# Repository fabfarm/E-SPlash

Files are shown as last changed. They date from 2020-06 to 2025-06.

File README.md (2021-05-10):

# FabLab Irrigation System

## Design

C++ for a Microprocessor that includes an embedded http server.

The http server displays controls for N zones, where each zone has:

- turn on time
- turn on duration

```
Valve1 \
Valve2  --- Microprocessor <==> Web Interface  
ValveN /
```

## Web server methods

| **Endpoint** | **Purpose** |
|---|---|
| /getData | returns json |
| /updateData  | gets updated json |

## Core Logic

1) start with our json object.
2) we get new data (temp/humidit/y/relay status)
3) update the json object
4) serialize ==> json
5) return json to html

**State Problem**  
When the microcontroller loses power, we lose state. We therefore need to persist settings to disk.

- Settings are *read* from disk on startup
- Settings are *saved* each time a user changes settings in the web ui
- Settings are kept in memory and we check against them

Psuedo code:
```
Startup: 
  - read json to doc obj
  - init wifi
  - init http server

/getData
  - serialize doc obj to Json
  - return Json to caller
  - no logic

/updateData 
  - take incoming Json and save it to disk
  - arduinoJson magically serializes incoming request to our doc object for free
  - no logic 

Loop (no disk i/o):
  - examine current state of in memory doc object and take action
```

## Data format

```json
{
    "data": {
        "currentTime": "Tuesday, June 23 2020 11:54:16",
        "temperature": "29.90",
        "humidity": "51.00",
        "override": 0,
        "ssid": "myssid",
        "pass": "my password"
    },
    "relays": [
        {
            "name": "Fruit Tree",
            "pin": 25,
            "isRunning": 1,
            "isEnabled": 0,
            "times": [
                {
                    "startTime": "03:00",
                    "duration": "0"
                }
            ]
        },
        {
            "name": "Vegie Garden",
            "pin": 26,
            "isRunning": 1,
            "isEnabled": 0,
            "status": 1,
            "times": [
                {
                    "startTime": "12:00",
                    "duration": "0"
                },
                {
                    "startTime": "12:30",
                    "duration": "0"
                }
            ]
        },
        {
            "name": "Cypress Hill",
            "pin": 33,
            "isRunning": 1,
            "isEnabled": 0,
            "status": 1,
            "times": [
                {
                    "startTime": "12:45",
                    "duration": "0"
                },
                {
                    "startTime": "10:00",
                    "duration": "0"
                },
                {
                    "startTime": "16:45",
                    "duration": "0"
                }
            ]
        }
    ]
}

```

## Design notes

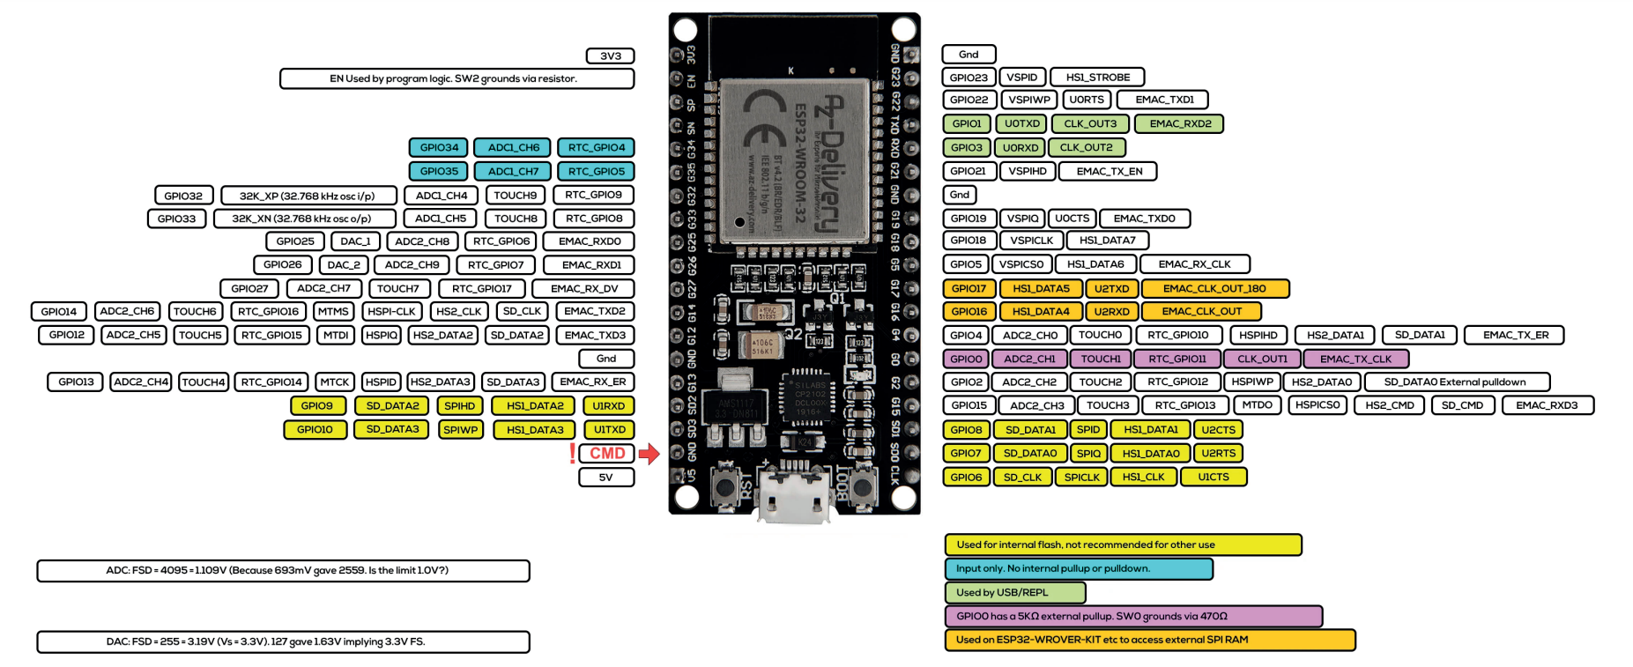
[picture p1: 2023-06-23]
Firmware/temp/Screenshot 2023-06-19 192932.png

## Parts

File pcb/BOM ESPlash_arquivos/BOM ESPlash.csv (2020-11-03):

Value | Coluna1 | Package | Description | Qty | Unit Price | Total Price
PCB blank |  |  | Proto Board Copper Clad FR1, Single Sided, 1 oz. 5.00" x 4.00" (127.0mm x 101.6mm) | 1 | $2.44 | $2.44
FTDI-SMD-HEADER |  | 1X06SMD | CONN HEADER R/A 6POS 2.54MM | 1 | $0.18 | $0.18
22-23-2021 |  | 22-23-2021 | CONN HEADER VERT 2POS 2.54MM | 1 | $0.17 | $0.17
header2x6 |  | 2X03 | CONN HEADER VERT 6POS 2.54MM | 2 | $0.48 | $0.96
SWITCH | SWITCH | SWITCH TACTILE SPST-NO 50MA 12V | SWITCH TACTILE SPST-NO 50MA 12V | 2 | $0.20 | $0.40
0.1uF | Capacitor | C1206FAB | CAP CER 0.1UF 50V X7R 1206 | 2 | $0.11 | $0.22
100uF | Capacitor | C1206FAB | CAP CER 100UF 10V X5R 1206 | 1 | $1.49 | $1.49
15pf | Capacitor | C1206FAB | CAP CER 15PF 50V 1206 | 2 | $0.19 | $0.38
1nF | Capacitor | C1206FAB | CAP CER 1206 1NF 250V X7R 10% | 1 | $0.27 | $0.27
ESP32-WROOM-32 (16MB) |  | ESP-WROOM-32 | WIFI MODULE 128MBITS SPI FLASH | 1 | $4.50 | $4.50
LED | LED | LED1206 | Standard LEDs - SMD 1206 Blue | 7 | $1.45 | $10.15
100ohm | Resistor | R1206 | RES SMD 100 OHM 1% 1/4W 1206 | 5 | $0.57 | $2.85
10k | Resistor | R1206 | RES SMD 10K OHM 1% 1/4W 1206 | 3 | $0.57 | $1.71
1.2Mohm | Resistor | R1206 | RES SMD 1.2M OHM 1% 1/4W 1206 | 1 | $0.10 | $0.10
1.5Mohm | Resistor | R1206 | RES SMD 1.5M OHM 1% 1/4W 1206 | 1 | $0.18 | $0.18
150ohm | Resistor | R1206 | RES SMD 15 OHM 1% 1/4W 1206 | 2 | $0.10 | $0.20
1K | Resistor | R1206 | RES SMD 1K OHM 1% 1/4W 1206 | 4 | $0.57 | $2.28
220omh | Resistor | R1206 | RES SMD 220 OHM 1% 1/4W 1206 | 4 | $0.10 | $0.40
SRD-05VDC-SL-C | Relay | RELAY_SRD-05VDC-SL-C | SRD-5VDC-SL-C 5 Pin PCB Type | 4 | $1.99 | $7.96
ACS712 |  | SO08 | SENSOR CURRENT HALL 20A AC/DC | 1 | $2.32 | $2.32
 |  | SOD123 | DIODE GEN PURP 100V 200MA SOD123 | 4 | $0.13 | $0.52
EL817(S)(D)(TU)-V |  | SOIC254P1030X460-4N | OPTOISOLTR 5KV TRANSISTOR 4-DIP | 4 | $0.18 | $0.72
BCX70SMD |  | SOT23 | TRANS NPN 45V 0.1A SOT23 | 4 | $0.19 | $0.76
MCP1700T-3302E/TT |  | SOT95P237X112-3N | IC REG LINEAR 3.3V 250MA SOT23-3 | 1 | $0.37 | $0.37
TEMP-HUM-SENSOR-DHT11 |  | TEMP-HUM-SENSOR-DHT11 | SENSOR HUMID/TEMP 5V DTL 5% MOD | 1 | $5.00 | $5.00
 |  | W237-102 | WAGO SCREW CLAMP | 4 | $0.10 | $0.40
ECS-.327-12.5-13X |  | XTAL_ECS-.327-12.5-13X | CRYSTAL 32.7680KHZ 12.5PF TH | 1 | $0.24 | $0.24
 |  |  |  |  | Total | $44.73

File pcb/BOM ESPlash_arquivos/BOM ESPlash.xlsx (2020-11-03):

Value | Package | Description | Links | Qty | Unit Price | Total Price
PCB blank |  | Proto Board Copper Clad FR1, Single Sided, 1 oz. 5.00" x 4.00" (127.0mm x 101.6mm) (https://www.digikey.com/product-detail/en/bantam-tools/MT1004/1932-1038-ND/8567212) | https://www.digikey.com/product-detail/en/bantam-tools/MT1004/1932-1038-ND/8567212 | 1 | $2.44 | $2.44
FTDI-SMD-HEADER | 1X06SMD | CONN HEADER R/A 6POS 2.54MM (https://www.digikey.com/product-detail/en/adam-tech/PH1RB-06-UA/2057-PH1RB-06-UA-ND/9830592) | https://www.digikey.com/product-detail/en/adam-tech/PH1RB-06-UA/2057-PH1RB-06-UA-ND/9830592 | 1 | $0.18 | $0.18
22-23-2021 | 22-23-2021 | CONN HEADER VERT 2POS 2.54MM (https://www.digikey.com/products/en?keywords=22-23-2021) | https://www.digikey.com/products/en?keywords=22-23-2021 | 1 | $0.17 | $0.17
header2x6 | 2X03 | CONN HEADER VERT 6POS 2.54MM (https://www.digikey.com/product-detail/en/samtec-inc/TSW-103-07-F-D/SAM10846-ND/2685876) | https://www.digikey.com/product-detail/en/samtec-inc/TSW-103-07-F-D/SAM10846-ND/2685876 | 2 | $0.48 | $0.96
SWITCH | SWITCH TACTILE SPST-NO 50MA 12V | SWITCH TACTILE SPST-NO 50MA 12V (https://www.digikey.com/product-detail/en/e-switch/TL3305BF260QG/EG5354CT-ND/5816199) | https://www.digikey.com/product-detail/en/e-switch/TL3305BF260QG/EG5354CT-ND/5816199 | 2 | $0.20 | $0.40
0.1uF | C1206FAB | CAP CER 0.1UF 50V X7R 1206 (https://www.digikey.com/product-detail/en/kemet/C1206C104K5RAC7800/399-C1206C104K5RAC7800CT-ND/411524) | https://www.digikey.com/product-detail/en/kemet/C1206C104K5RAC7800/399-C1206C104K5RAC7800CT-ND/411524 | 2 | $0.11 | $0.22
100uF | C1206FAB | CAP CER 100UF 10V X5R 1206 (https://www.digikey.com/product-detail/en/tdk-corporation/C3216X5R1A107M160AC/445-6007-1-ND/2444048) | https://www.digikey.com/product-detail/en/tdk-corporation/C3216X5R1A107M160AC/445-6007-1-ND/2444048 | 1 | $1.49 | $1.49
15pf | C1206FAB | CAP CER 15PF 50V 1206 (https://www.digikey.com/product-detail/en/kemet/C1206C150K5GACTU/399-9314-1-ND/3522832) | https://www.digikey.com/product-detail/en/kemet/C1206C150K5GACTU/399-9314-1-ND/3522832 | 2 | $0.19 | $0.38
1nF | C1206FAB | CAP CER 1206 1NF 250V X7R 10% (https://www.digikey.com/product-detail/en/kemet/C1206C102KARECAUTO/399-17173-1-ND/8563714) | https://www.digikey.com/product-detail/en/kemet/C1206C102KARECAUTO/399-17173-1-ND/8563714 | 1 | $0.27 | $0.27
ESP32-WROOM-32 (16MB) | ESP-WROOM-32 | WIFI MODULE 128MBITS SPI FLASH (https://www.digikey.com/product-detail/en/espressif-systems/ESP32-WROOM-32-16MB/1904-1020-2-ND/9381713) | https://www.digikey.com/product-detail/en/espressif-systems/ESP32-WROOM-32-16MB/1904-1020-2-ND/9381713 | 1 | $4.50 | $4.50
LED | LED1206 | Standard LEDs - SMD 1206 Blue (https://eu.mouser.com/productdetail/lumex/sml-lx1206usbc-tr?qs=UWUCXFQQ%252bdkNnUihARaICw==) | https://eu.mouser.com/productdetail/lumex/sml-lx1206usbc-tr?qs=UWUCXFQQ%252bdkNnUihARaICw== | 7 | $1.45 | $10.15
100ohm | R1206 | RES SMD 100 OHM 1% 1/4W 1206 (https://www.digikey.com/product-detail/en/panasonic-electronic-components/ERA-8AEB101V/P100BCCT-ND/3069515) | https://www.digikey.com/product-detail/en/panasonic-electronic-components/ERA-8AEB101V/P100BCCT-ND/3069515 | 5 | $0.57 | $2.85
10k | R1206 | RES SMD 10K OHM 1% 1/4W 1206 (https://www.digikey.com/product-detail/en/bourns-inc/CRT1206-BY-1002ELF/CRT1206-BY-1002ELFCT-ND/1775051) | https://www.digikey.com/product-detail/en/bourns-inc/CRT1206-BY-1002ELF/CRT1206-BY-1002ELFCT-ND/1775051 | 3 | $0.57 | $1.71
1.2Mohm | R1206 | RES SMD 1.2M OHM 1% 1/4W 1206 (https://www.digikey.com/product-detail/en/panasonic-electronic-components/ERJ-8GEYJ125V/P1-2MECT-ND/203263) | https://www.digikey.com/product-detail/en/panasonic-electronic-components/ERJ-8GEYJ125V/P1-2MECT-ND/203263 | 1 | $0.10 | $0.10
1.5Mohm | R1206 | RES SMD 1.5M OHM 1% 1/4W 1206 (https://www.digikey.com/product-detail/en/rohm-semiconductor/KTR18EZPF1504/RHM1-5MAICT-ND/4071441) | https://www.digikey.com/product-detail/en/rohm-semiconductor/KTR18EZPF1504/RHM1-5MAICT-ND/4071441 | 1 | $0.18 | $0.18
150ohm | R1206 | RES SMD 15 OHM 1% 1/4W 1206 (https://www.digikey.com/product-detail/en/yageo/RC1206JR-07150RL/311-150ERCT-ND/732170) | https://www.digikey.com/product-detail/en/yageo/RC1206JR-07150RL/311-150ERCT-ND/732170 | 2 | $0.10 | $0.20
1K | R1206 | RES SMD 1K OHM 1% 1/4W 1206 (https://www.digikey.com/product-detail/en/panasonic-electronic-components/ERA-8AEB102V/P1-0KBCCT-ND/3069520) | https://www.digikey.com/product-detail/en/panasonic-electronic-components/ERA-8AEB102V/P1-0KBCCT-ND/3069520 | 4 | $0.57 | $2.28
220omh | R1206 | RES SMD 220 OHM 1% 1/4W 1206 (https://www.digikey.com/product-detail/en/stackpole-electronics-inc/RMCF1206FT220R/RMCF1206FT220RCT-ND/2418647) | https://www.digikey.com/product-detail/en/stackpole-electronics-inc/RMCF1206FT220R/RMCF1206FT220RCT-ND/2418647 | 4 | $0.10 | $0.40
SRD-05VDC-SL-C | RELAY_SRD-05VDC-SL-C | SRD-5VDC-SL-C 5 Pin PCB Type (https://www.banggood.com/Mini-5V-DC-Power-Relay-SRD-5VDC-SL-C-5-Pin-PCB-Type-p-930170.html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) | https://www.banggood.com/Mini-5V-DC-Power-Relay-SRD-5VDC-SL-C-5-Pin-PCB-Type-p-930170.html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 | 4 | $1.99 | $7.96
ACS712 | SO08 | SENSOR CURRENT HALL 20A AC/DC (https://www.digikey.com/product-detail/en/allegro-microsystems/ACS712ELCTR-20A-T/620-1190-2-ND/1284594) | https://www.digikey.com/product-detail/en/allegro-microsystems/ACS712ELCTR-20A-T/620-1190-2-ND/1284594 | 1 | $2.32 | $2.32
Diode | SOD123 | DIODE GEN PURP 100V 200MA SOD123 (https://www.digikey.com/product-detail/en/on-semiconductor/MMSD4148T1G/MMSD4148T1GOSCT-ND/1121611) | https://www.digikey.com/product-detail/en/on-semiconductor/MMSD4148T1G/MMSD4148T1GOSCT-ND/1121611 | 4 | $0.13 | $0.52
EL817(S)(D)(TU)-V | SOIC254P1030X460-4N | OPTOISOLTR 5KV TRANSISTOR 4-DIP (https://www.digikey.com/product-detail/en/everlight-electronics-co-ltd/EL817/EL817-ND/2693260) | https://www.digikey.com/product-detail/en/everlight-electronics-co-ltd/EL817/EL817-ND/2693260 | 4 | $0.18 | $0.72
BCX70SMD | SOT23 | TRANS NPN 45V 0.1A SOT23 (https://www.digikey.com/product-detail/en/nexperia-usa-inc/BCX70K-215/1727-4918-1-ND/2531422) | https://www.digikey.com/product-detail/en/nexperia-usa-inc/BCX70K-215/1727-4918-1-ND/2531422 | 4 | $0.19 | $0.76
MCP1700T-3302E/TT | SOT95P237X112-3N | IC REG LINEAR 3.3V 250MA SOT23-3 (https://www.digikey.com/product-detail/en/microchip-technology/MCP1700T-3302E-TT/MCP1700T3302ETTCT-ND/652677) | https://www.digikey.com/product-detail/en/microchip-technology/MCP1700T-3302E-TT/MCP1700T3302ETTCT-ND/652677 | 1 | $0.37 | $0.37
TEMP-HUM-SENSOR-DHT11 | TEMP-HUM-SENSOR-DHT11 | SENSOR HUMID/TEMP 5V DTL 5% MOD (https://www.digikey.com/products/en/sensors-transducers/humidity-moisture-sensors/529?k=DHT11) | https://www.digikey.com/products/en/sensors-transducers/humidity-moisture-sensors/529?k=DHT11 | 1 | $5.00 | $5.00
Screw Clamp | W237-102 | WAGO SCREW CLAMP (https://www.aliexpress.com/item/33038876365.html) | https://www.aliexpress.com/item/33038876365.html | 4 | $0.10 | $0.40
ECS-.327-12.5-13X | XTAL_ECS-.327-12.5-13X | CRYSTAL 32.7680KHZ 12.5PF TH (https://www.digikey.com/products/en?keywords=ECS-.327-12.5-13X) | https://www.digikey.com/products/en?keywords=ECS-.327-12.5-13X | 1 | $0.24 | $0.24
 |  |  |  |  | Total | $44.73
Materials and components | What for | Where they come from | Links | Qty | Unit Price | Total Price
MDF Forescolor | for the enclosure | Fablab Stock | http://www.forescolor.com/product/ | 900 | $0.000027 | $0.02
Silicone | for the gasket | fablab stock | https://www.amazon.es/LETS-RESIN-silicona-relaci%C3%B3n-manualmente/dp/B07V5FFPWC | 50 | $0.05 | $2.39
Epoxy resin (https://www.amazon.es/gp/product/B07KQ6Q5CB/ref=ppx_yo_dt_b_asin_title_o04_s00?ie=UTF8&psc=1) | to further waterproof the interior of the enclosure and help with the light refraction of the LEDs | fablab stock | https://www.amazon.es/gp/product/B07KQ6Q5CB/ref=ppx_yo_dt_b_asin_title_o04_s00?ie=UTF8&psc=1 | 50 | $0.01 | $0.60
 |  |  |  |  | Total | $3.01

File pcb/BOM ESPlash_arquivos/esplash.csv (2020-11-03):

Qty | Value | Device | Package | Parts | Description | ARROW_AMERICAS-PURCHASE-URL | AVAILABILITY | DESCRIPTION | DIGIKEY-PURCHASE-URL | MF | MOUSER-PURCHASE-URL | MP | MPN | OC_FARNELL | OC_NEWARK | PACKAGE | POPULARITY | PRICE
4 |  | DIODESOD123 | SOD123 | D1, D2, D3, D4 | DIODE
4 |  | W237-102 | W237-102 | ACIN/OUT, VALVESOLENOID_01, VALVESOLENOID_02, VALVESOLENOID_03 | WAGO SCREW CLAMP |  |  |  |  |  |  |  | 237-102 | unknown | 70K9898
1 | 0.1uF | CAP-UNPOLARIZEDFAB | C1206FAB | C4
1 | 1.2Mohm | RES-US1206FAB | R1206FAB | R7 | Resistor (US Symbol)
1 | 1.5Mohm | RES-US1206FAB | R1206FAB | R9 | Resistor (US Symbol)
1 | 100nF | CAP-UNPOLARIZEDFAB | C1206FAB | C1
3 | 100ohm | RES-US1206 | R1206 | R13, R14, R16 | Resistor (US Symbol)
2 | 100ohm | RES-US1206FAB | R1206FAB | R6, R8 | Resistor (US Symbol)
1 | 100uF | CAP-US1206FAB | C1206FAB | C2
1 | 10K | RES-US1206FAB | R1206FAB | R10 | Resistor (US Symbol)
2 | 10k | RES-US1206 | R1206 | R12, R15 | Resistor (US Symbol)
2 | 150ohm | RES-US1206FAB | R1206FAB | R3, R11 | Resistor (US Symbol)
2 | 15pf | CAP-UNPOLARIZEDFAB | C1206FAB | C5, C6
4 | 1K | RES-US1206FAB | R1206FAB | R1, R2, R4, R5 | Resistor (US Symbol)
1 | 1nF | CAP-UNPOLARIZEDFAB | C1206FAB | C3
1 | 22-23-2021 | 22-23-2021 | 22-23-2021 | POWER | .100 (2.54mm) Center Header - 2 Pin" |  |  |  |  | MOLEX |  |  | 22-23-2021 | 1462926 | 25C3832 |  | 40
4 | 220omh | RES-US1206FAB | R1206FAB | R17, R18, R19, R20 | Resistor (US Symbol)
1 | ACS712 | ACS712 | SO08 | IC1
4 | BCX70SMD | BCX70SMD | SOT23 | Q1, Q2, Q3, Q4 | NPN TRANSISTOR |  |  |  |  |  |  |  |  |  |  |  | 0
1 | ECS-.327-12.5-13X | ECS-.327-12.5-13X | XTAL_ECS-.327-12.5-13X | Y1 | Crystal Cylindrical Can, Radial |  | Unavailable | 32.768kHz ±20ppm Crystal 12.5pF 35 kOhms Cylindrical Can, Radial |  | ECS Inc. |  | ECS-.327-12.5-13X |  |  |  | Cylindrical Can Radial ECS International |  | None
4 | EL817(S)(D)(TU)-V | EL817(S)(D)(TU)-V | SOIC254P1030X460-4N | U2, U3, U4, U5 | Optocoupler DC-IN 1-CH Transistor DC-OUT 4-Pin PDIP Tube |  | Unavailable | Optoisolator Transistor Output 5000Vrms 1 Channel 4-SMD |  | Everlight Electronics |  | EL817(S)(D)(TU)-V |  |  |  | SMD-4 Everlight |  | None
1 | ESP-WROOM-32 | ESP-WROOM-32 | ESP-WROOM-32 | U1 | Espressif Systems ESP-WROOM-32
1 | FTDI-SMD-HEADER | FTDI-SMD-HEADER | 1X06SMD | RTS
1 | GPIO0 Button | 6MM_SWITCH6MM_SWITCH | 6MM_SWITCH | S2 | OMRON SWITCH
3 | LED | LED | LED1206 | U$7, U$9, U$10 | LED
4 | LEDFAB1206 | LEDFAB1206 | LED1206FAB | U$1, U$3, U$4, U$5 | LED
1 | MCP1700T-3302E/TT | MCP1700T-3302E/TT | SOT95P237X112-3N | U$2 |  | https://snapeda.com/shop?store=Arrow+Americas&id=4791194 | Unavailable | IC REG LINEAR 3.3V 250MA SOT23-3 | https://snapeda.com/shop?store=DigiKey&id=4791194 | Microchip Technology | https://snapeda.com/shop?store=Mouser&id=4791194 | MCP1700T-3302E/TT |  |  |  | None |  | None
1 | Reset | 6MM_SWITCH6MM_SWITCH | 6MM_SWITCH | S1 | OMRON SWITCH
4 | SRD-05VDC-SL-C | SRD-05VDC-SL-C | RELAY_SRD-05VDC-SL-C | K1, K2, K3, K4 | 5V Trigger Relay Module For Arduino And Raspberry Pi 5V Trigger Relay Module For Arduino And Raspberry Pi |  | Unavailable | 5V Trigger Relay Module For Arduino And Raspberry Pi 5V Trigger Relay Module For Arduino And Raspberry Pi |  | Songle Relay |  | SRD-05VDC-SL-C |  |  |  | None |  | None
1 | TEMP-HUM-SENSOR-DHT11 | TEMP-HUM-SENSOR-DHT11 | TEMP-HUM-SENSOR-DHT11 | U$6 | DHT11 - digital humidity & temperature sensor
2 | header2x6 | PINHD-2X3 | 2X03 | JP1, JP2 | PIN HEADER |  |  |  |  |  |  |  |  |  |  |  | 62

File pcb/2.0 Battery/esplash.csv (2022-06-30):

Part | Value | Device | Package | Description | ARROW_AMERICAS-PURCHASE-URL | AVAILABILITY | DESCRIPTION | DIGIKEY-PURCHASE-URL | MF | MOUSER-PURCHASE-URL | MP | MPN | OC_FARNELL | OC_NEWARK | PACKAGE | POPULARITY | PRICE
C1 | 100nF | CAP-UNPOLARIZEDFAB | C1206FAB
C2 | 100uF | CAP-US1206FAB | C1206FAB
C5 | 15pf | CAP-UNPOLARIZEDFAB | C1206FAB
C6 | 15pf | CAP-UNPOLARIZEDFAB | C1206FAB
GND1 | SC | W237-103 | W237-103 | WAGO SCREW CLAMP |  |  |  |  |  |  |  | 237-103 | unknown | 18M7116 |  | 5
POWER | 22-23-2021 | 22-23-2021 | 22-23-2021 | .100 (2.54mm) Center Header - 2 Pin" |  |  |  |  | MOLEX |  |  | 22-23-2021 | 1462926 | 25C3832 |  | 40
Q5 | BCX70SMD | BCX70SMD | SOT23 | NPN TRANSISTOR |  |  |  |  |  |  |  |  |  |  |  | 0
Q6 | BCX70SMD | BCX70SMD | SOT23 | NPN TRANSISTOR |  |  |  |  |  |  |  |  |  |  |  | 0
R1 | 100ohm | RES-US1206 | R1206 | Resistor (US Symbol)
R2 | 100ohm | RES-US1206 | R1206 | Resistor (US Symbol)
R4 | 100ohm | RES-US1206 | R1206 | Resistor (US Symbol)
R5 | 100ohm | RES-US1206 | R1206 | Resistor (US Symbol)
R6 | 100ohm | RES-US1206 | R1206 | Resistor (US Symbol)
R7 | 1.2Mohm | RES-US1206FAB | R1206FAB | Resistor (US Symbol)
R8 | 100ohm | RES-US1206 | R1206 | Resistor (US Symbol)
R9 | 1.5Mohm | RES-US1206FAB | R1206FAB | Resistor (US Symbol)
R10 | 10K | RES-US1206FAB | R1206FAB | Resistor (US Symbol)
R11 | 100ohm | RES-US1206 | R1206 | Resistor (US Symbol)
R12 | 10k | RES-US1206 | R1206 | Resistor (US Symbol)
R13 | 100ohm | RES-US1206 | R1206 | Resistor (US Symbol)
R14 | 100ohm | RES-US1206 | R1206 | Resistor (US Symbol)
R15 | 10k | RES-US1206 | R1206 | Resistor (US Symbol)
R16 | 100ohm | RES-US1206 | R1206 | Resistor (US Symbol)
R17 | 100ohm | RES-US1206 | R1206 | Resistor (US Symbol)
R18 | 100ohm | RES-US1206 | R1206 | Resistor (US Symbol)
R19 | 100ohm | RES-US1206 | R1206 | Resistor (US Symbol)
R21 | 10k | RES-US1206 | R1206 | Resistor (US Symbol)
R22 | 10k | RES-US1206 | R1206 | Resistor (US Symbol)
RTS | FTDI-SMD-HEADER | FTDI-SMD-HEADER | 1X06SMD
S1 | Reset | 6MM_SWITCH6MM_SWITCH | 6MM_SWITCH | OMRON SWITCH
S2 | GPIO0 Button | 6MM_SWITCH6MM_SWITCH | 6MM_SWITCH | OMRON SWITCH
SC_00 | SC | W237-103 | W237-103 | WAGO SCREW CLAMP |  |  |  |  |  |  |  | 237-103 | unknown | 18M7116 |  | 5
SC_01 | SC | W237-103 | W237-103 | WAGO SCREW CLAMP |  |  |  |  |  |  |  | 237-103 | unknown | 18M7116 |  | 5
SC_02 | SC | W237-103 | W237-103 | WAGO SCREW CLAMP |  |  |  |  |  |  |  | 237-103 | unknown | 18M7116 |  | 5
SC_03 | SC | W237-103 | W237-103 | WAGO SCREW CLAMP |  |  |  |  |  |  |  | 237-103 | unknown | 18M7116 |  | 5
SC_04 | SC | W237-103 | W237-103 | WAGO SCREW CLAMP |  |  |  |  |  |  |  | 237-103 | unknown | 18M7116 |  | 5
SC_05 | SC | W237-103 | W237-103 | WAGO SCREW CLAMP |  |  |  |  |  |  |  | 237-103 | unknown | 18M7116 |  | 5
SC_06 | SC | W237-103 | W237-103 | WAGO SCREW CLAMP |  |  |  |  |  |  |  | 237-103 | unknown | 18M7116 |  | 5
SC_07 | SC | W237-103 | W237-103 | WAGO SCREW CLAMP |  |  |  |  |  |  |  | 237-103 | unknown | 18M7116 |  | 5
SC_08 | SC | W237-103 | W237-103 | WAGO SCREW CLAMP |  |  |  |  |  |  |  | 237-103 | unknown | 18M7116 |  | 5
U$1 | LED | LED | LED1206 | LED
U$2 | MCP1700T-3302E/TT | MCP1700T-3302E/TT | SOT95P237X112-3N |  | https://snapeda.com/shop?store=Arrow+Americas&id=4791194 | Unavailable | IC REG LINEAR 3.3V 250MA SOT23-3 | https://snapeda.com/shop?store=DigiKey&id=4791194 | Microchip Technology | https://snapeda.com/shop?store=Mouser&id=4791194 | MCP1700T-3302E/TT |  |  |  | None |  | None
U$3 | LED | LED | LED1206 | LED
U$5 | LED | LED | LED1206 | LED
U$6 | TEMP-HUM-SENSOR-DHT11 | TEMP-HUM-SENSOR-DHT11 | TEMP-HUM-SENSOR-DHT11 | DHT11 - digital humidity & temperature sensor
U$7 | LED | LED | LED1206 | LED
U$8 | LED | LED | LED1206 | LED
U$9 | LED | LED | LED1206 | LED
U$10 | LED | LED | LED1206 | LED
U$11 | LED | LED | LED1206 | LED
U$12 | LED | LED | LED1206 | LED
U$13 | LED | LED | LED1206 | LED
U$14 | LED | LED | LED1206 | LED
U$15 | LED | LED | LED1206 | LED
U$16 | LED | LED | LED1206 | LED
U1 | ESP-WROOM-32 | ESP-WROOM-32 | ESP-WROOM-32 | Espressif Systems ESP-WROOM-32
Y1 | ECS-.327-12.5-13X | ECS-.327-12.5-13X | XTAL_ECS-.327-12.5-13X | Crystal Cylindrical Can, Radial |  | Unavailable | 32.768kHz ±20ppm Crystal 12.5pF 35 kOhms Cylindrical Can, Radial |  | ECS Inc. |  | ECS-.327-12.5-13X |  |  |  | Cylindrical Can Radial ECS International |  | None

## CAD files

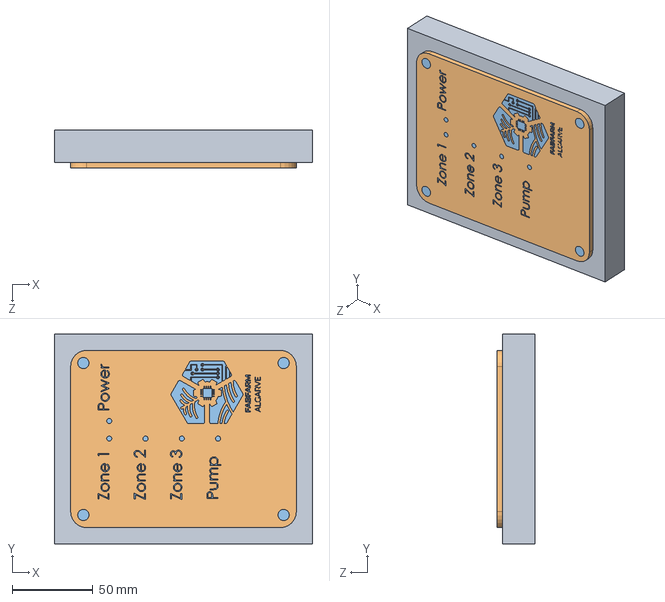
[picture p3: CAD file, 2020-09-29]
board_enclosure/to_cnc.SLDASM
160.0 x 130.0 x 23.5 mm
template
block2

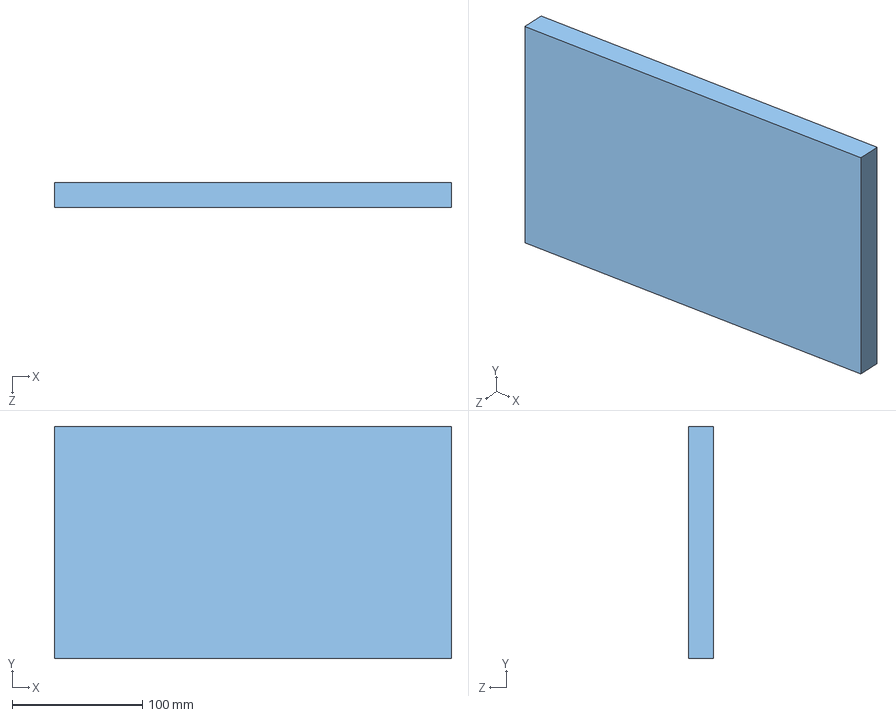
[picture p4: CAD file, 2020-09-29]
board_enclosure/toCNCA.SLDASM
304.4 x 178.2 x 19.0 mm
box_top
box_bottom

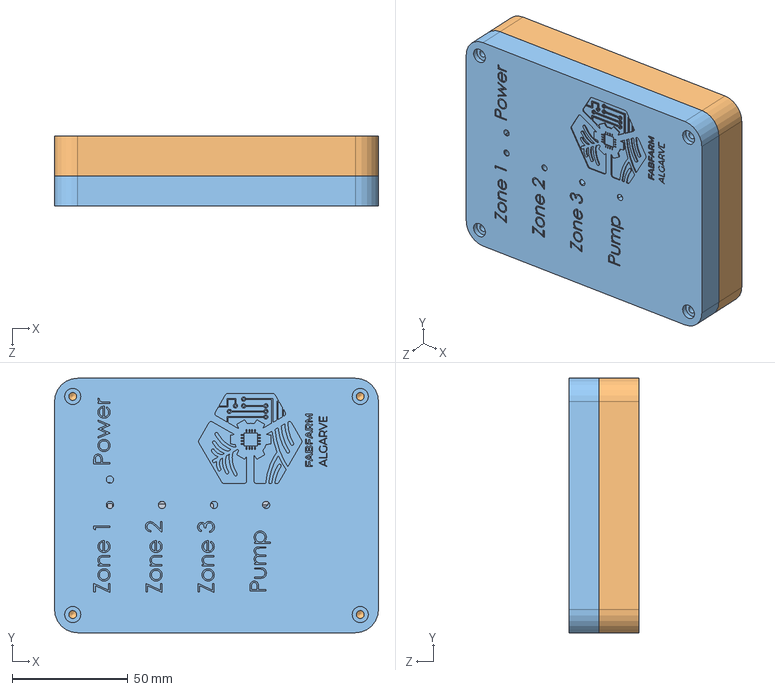
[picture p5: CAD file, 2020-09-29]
board_enclosure/E-SPlash_project.SLDASM
140.0 x 110.0 x 30.4 mm
esplash
box_bottom

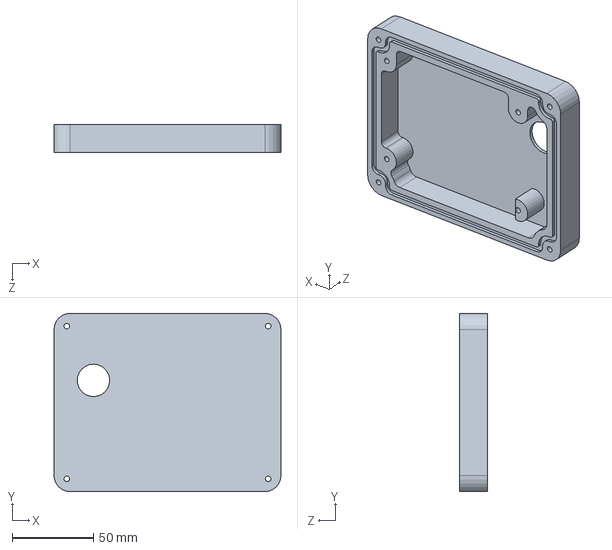
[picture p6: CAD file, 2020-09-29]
board_enclosure/box_bottom.SLDPRT
140.0 x 110.0 x 17.4 mm

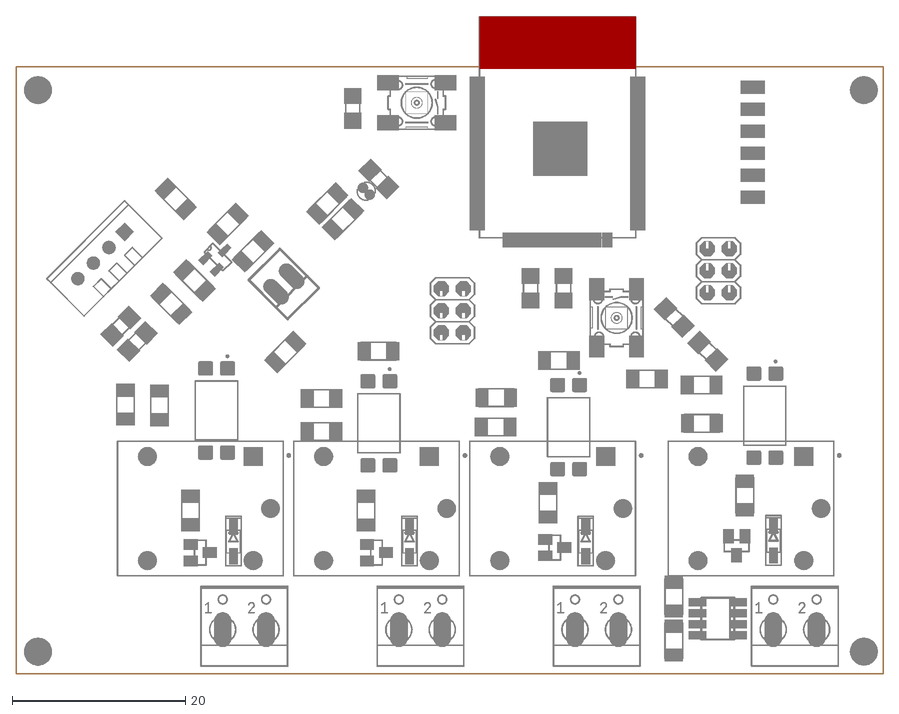
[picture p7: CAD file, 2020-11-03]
pcb/BOM ESPlash_arquivos/esplash.dxf
100.0 x 75.8

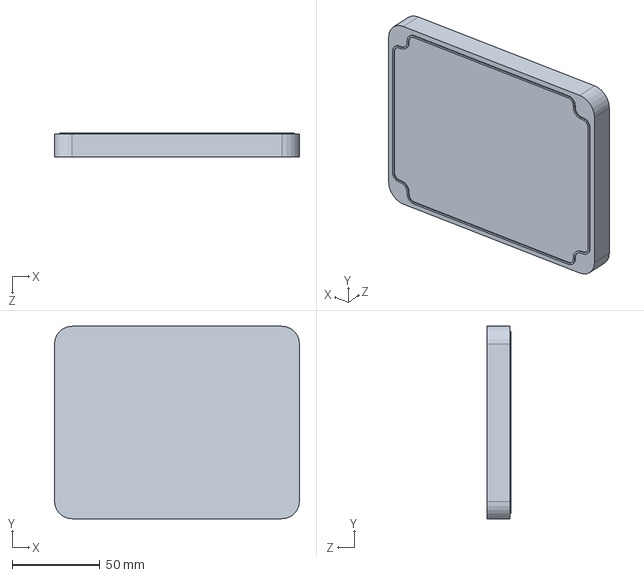
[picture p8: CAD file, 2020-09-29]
board_enclosure/block2.SLDPRT
140.0 x 110.0 x 13.5 mm

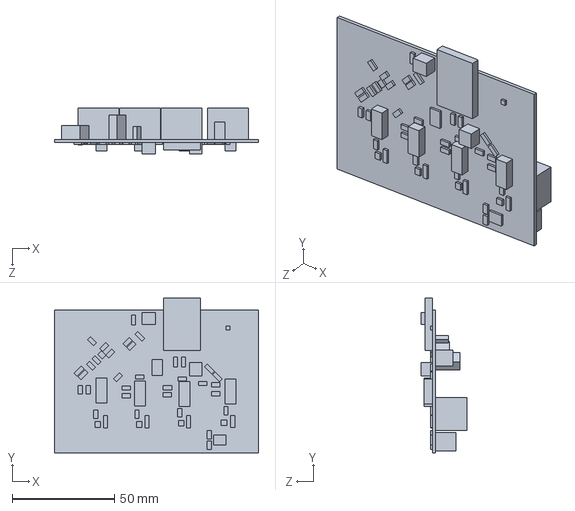
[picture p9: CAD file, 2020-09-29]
board_enclosure/esplash.SLDPRT
100.0 x 75.8 x 22.4 mm

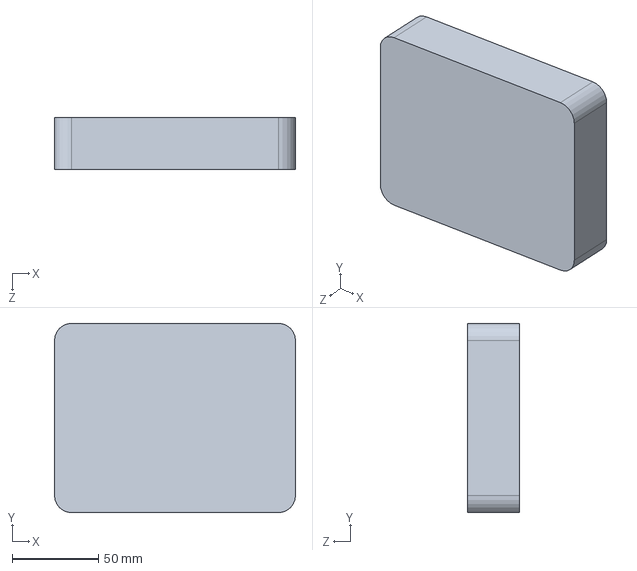
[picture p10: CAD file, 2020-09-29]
board_enclosure/block.SLDPRT
140.0 x 110.0 x 30.0 mm

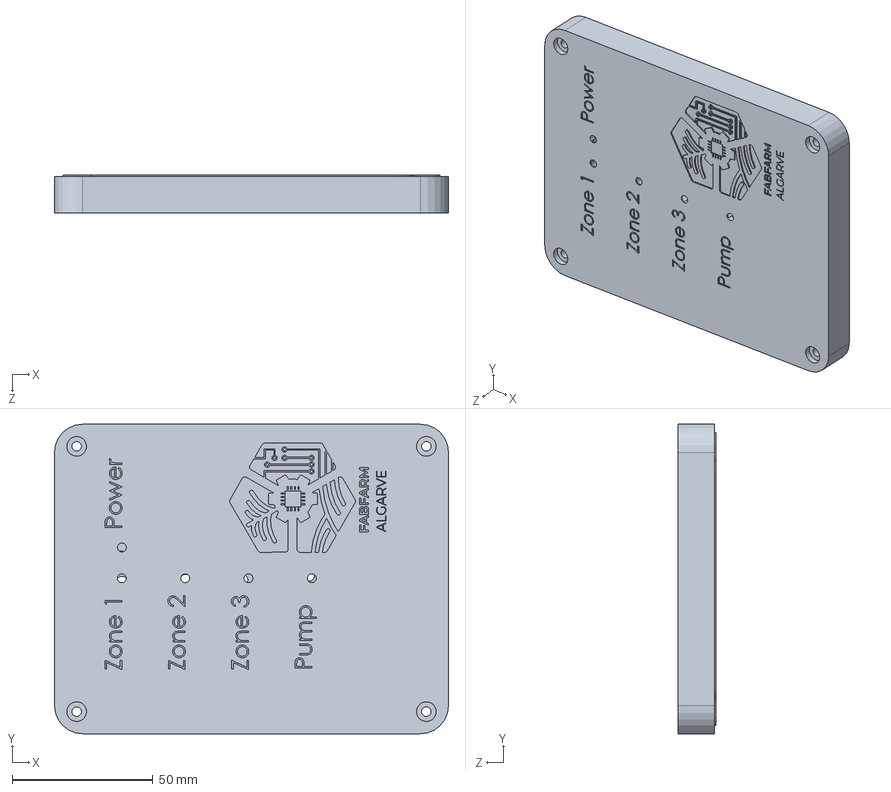
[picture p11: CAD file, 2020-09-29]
board_enclosure/box_top.SLDPRT
140.0 x 110.0 x 13.5 mm

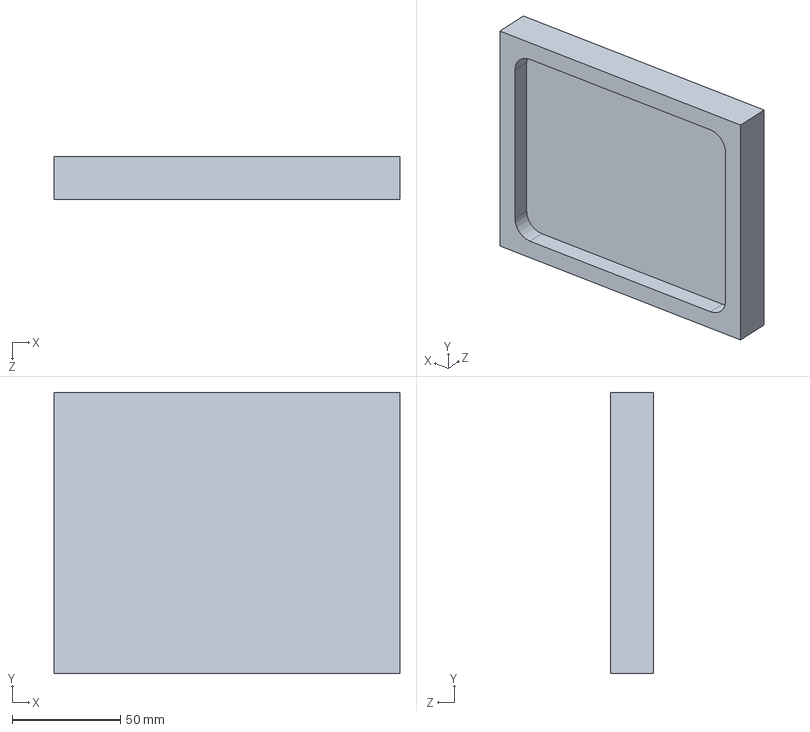
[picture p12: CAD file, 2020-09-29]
board_enclosure/template.SLDPRT
160.0 x 130.0 x 20.0 mm

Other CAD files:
board_enclosure/Part1.SLDPRT
board_enclosure/box_bottom.STL
board_enclosure/box_top.STL

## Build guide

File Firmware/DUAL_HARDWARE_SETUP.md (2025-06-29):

# Dual Hardware Configuration

This project supports two hardware configurations with all pins defined in `platformio.ini`:

## Hardware 1: Custom PCB (Default)
**Environment:** `esp32doit-devkit-v1`

```bash
pio run --environment esp32doit-devkit-v1
# or simply
pio run
```

**Pin Configuration:**
- Relay 1: GPIO 27
- Relay 2: GPIO 26  
- Relay 3: GPIO 25
- Pump: GPIO 33

## Hardware 2: LILYGO T-Relay 4CH
**Environment:** `lilygo-t-relay-4ch`

```bash
pio run --environment lilygo-t-relay-4ch
```

**Pin Configuration:**
- Relay 1: GPIO 21
- Relay 2: GPIO 19
- Relay 3: GPIO 18
- Relay 4: GPIO 5
- Pump: GPIO 21 (same as Relay 1)

## How It Works

All hardware configuration is now handled in `platformio.ini` using build flags:

- All pin definitions are set as `-D` flags in each environment
- WiFi hostname and AP configuration are defined as build flags
- The `T_RELAY_4CH` flag distinguishes between hardware types
- No separate Board_Config files needed - everything is in platformio.ini

## Files Modified

- `platformio.ini`: Contains all pin definitions and configuration strings as build flags
- `Config.cpp`: Uses build flag defines instead of Board_Config structure

## Testing

Both configurations have been tested and compile successfully:
- Custom PCB: ✅ Success (15.65 seconds)
- LILYGO T-Relay: ✅ Success (15.20 seconds)

## Usage

1. **For Custom PCB**: Use default environment or specify `esp32doit-devkit-v1`
2. **For LILYGO T-Relay**: Specify `lilygo-t-relay-4ch` environment

All pin assignments and configurations are automatically applied based on the selected environment.

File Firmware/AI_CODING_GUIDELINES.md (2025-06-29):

# AI Coding Guidelines for FabFarm Irrigation Project

## CRITICAL RULES FOR AI ASSISTANTS

### 1. MAIN.CPP MUST REMAIN CLEAN
**DO NOT add any implementation code to `main.cpp`**

- `main.cpp` contains ONLY function calls
- All logic belongs in separate modules
- Keep the non-monolithic architecture
- New functionality goes in appropriate handler files

**Current main.cpp structure (PRESERVE THIS):**
```cpp
#include "Config.h"

void setup() {
  Serial.begin(9600);
  setupStorage();
  readDataJson();
  configureWiFiSettings();
  scanAvailableWiFiNetworks();
  initiateWiFiConnection();
  disableAllDevices();
  printCompilationTimestamp();
  initializeRtc();
  initializeServer();
  serverHandle();
}

void loop() {
  handleWiFiConnection();
  if (isScheduleMode) {
    scheduleMode();
  }
}
```

### 2. NO DELAY() FUNCTIONS ON ESP32
**NEVER use `delay()` with ESP32 web servers**

- ESP32 with web servers cannot afford to block
- Use `millis()` for timing instead
- Non-blocking code is mandatory

**Example - WRONG:**
```cpp
delay(1000); // NEVER DO THIS
```

**Example - CORRECT:**
```cpp
unsigned long previousMillis = 0;
const long interval = 1000;

unsigned long currentMillis = millis();
if (currentMillis - previousMillis >= interval) {
  previousMillis = currentMillis;
  // Do your timed action here
}
```

### 3. HARDWARE CONFIGURATION (FIXED)
**Pins are HARD-WIRED on PCB - DO NOT CHANGE:**
- Relay 1 (Fruit): Pin 27
- Relay 2 (Vegetables): Pin 26  
- Relay 3 (Water): Pin 25
- Pump: Pin 33

These are defined in `platformio.ini` build flags and cannot be modified.

### 4. MODULAR ARCHITECTURE
**Keep functionality separated in dedicated files:**
- `Config.h/.cpp` - Global configuration and variables
- `Board_Config.h/.cpp` - Hardware abstraction
- `WiFiHandler.h/.cpp` - WiFi management
- `WebServerManager.h/.cpp` - Web server and API endpoints
- `RelayHandler.h/.cpp` - Relay control logic
- `TimeHandler.h/.cpp` - Time and scheduling
- `JsonHandler.h/.cpp` - JSON parsing and creation
- `storageHandler.h/.cpp` - File system operations

### 5. IMPLEMENTATION GUIDELINES
- Add new functions to appropriate handler files
- Declare functions in corresponding `.h` files
- Include necessary headers in `Config.h` if globally needed
- Use consistent naming conventions
- Maintain existing code style

### 6. WEB SERVER CONSIDERATIONS
- All server endpoints in `WebServerManager.cpp`
- Use async web server patterns
- Avoid blocking operations in request handlers
- Keep response times minimal

### 7. WHAT NOT TO DO
- ❌ Add implementation code to `main.cpp`
- ❌ Use `delay()` functions
- ❌ Change hardware pin assignments
- ❌ Create monolithic functions
- ❌ Block the main loop
- ❌ Ignore the modular structure

### 8. WHEN ADDING NEW FEATURES
1. Identify the appropriate handler file
2. Add function declaration to `.h` file
3. Implement function in `.cpp` file
4. Add function call to appropriate location (usually in a handler, not main.cpp)
5. Test compilation
6. Maintain clean separation of concerns

**Remember: This project uses a clean, modular architecture. Keep it that way!**

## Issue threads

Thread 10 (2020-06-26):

if no internet located at boot system won't run

lpgn, 2020-06-26:
system won't run if no wifi connection present at boot, this prevents programs, schedules from running.
I believe I will have to add a battery to the system as a long term solution to keep time without the internet  and as a short term solution I will add a external RCT clock and have the wifi connection not mandatory for system initialization.

Closed 2020-06-26.

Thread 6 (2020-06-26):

relay flickering on, off, on, off...

lpgn, 2020-06-26:
When setting more than one schedule in the same zone with one enabled at x time and other not enabled relay turns on and then off rapidly, this is due to the current logic at the function scheduleMode() the loop has no logic to verify that another schedule is set and ends up turning off. @jknight

jknight, 2020-06-26:
bad code: this will cause checks for different schedules to compete and turn on and off over top of one another:
```
for each relay
    for each schedule
         if we are within this scheduled time then
                turn on
         else
              turn off
```

Good code: instead, we want to check them all first, then make an on/off decision after evaluating all options:

```
for each relay
   enableRelay = false
   for each schedule
       if we are within the scheduled time then
            enableRelay = true
   // done checking all the schedules - do any say we should be on? we only need one ! :)
   if enableRelay then turn on
   else turn off
```

Closed 2020-06-26.

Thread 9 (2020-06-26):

refresh time, humidity, temperature

lpgn, 2020-06-26:
currently data won't refresh without a manual refresh would be convenient to have a auto refresh on web interface.

Closed 2021-07-26.

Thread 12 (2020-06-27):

whachdog crach? reset?

lpgn, 2020-06-27:
Apparently if things hang for to long watchdog resets board. Was facing this from time to time.

Possible problems:
- internet not connected;
- to much delays;
- to much stuff going on in loop;
- wi-fi re-connection routine added to loop might be causing it.

According to this Stack Overflow answer: https://stackoverflow.com/questions/51750377/how-to-disable-interrupt-watchdog-in-esp32-or-increase-isr-time-limit

"You should always structure your code so that you do the least work you can in loop() and let it return. When it returns the software that supports your ESP32 application gets to do important housekeeping tasks, and reset the watchdog timer."

lpgn, 2020-06-27:
Connecting to WiFi..
now Manual Mode
E (56495) task_wdt: Task watchdog got triggered. The following tasks did not reset the watchdog in time:
E (56495) task_wdt:  - async_tcp (CPU 0/1)
E (56495) task_wdt: Tasks currently running:
E (56495) task_wdt: CPU 0: IDLE0
E (56495) task_wdt: CPU 1: IDLE1
E (56495) task_wdt: Aborting.
abort() was called at PC 0x400de5cb on core 0

Backtrace: 0x4008c434:0x3ffbe170 0x4008c665:0x3ffbe190 0x400de5cb:0x3ffbe1b0 0x40084771:0x3ffbe1d0 0x4016f773:0x3ffbc970 0x400df982:0x3ffbc990 0x4008a361:0x3ffbc9b0 0x40088b7d:0x3ffbc9d0

Rebooting...
        \UBV␗|��␞�*@�p␃␜�read file - BEGIN
{"data":{"currentTime":"Saturday, June 27 2020 11:42:59","temperature":"Failed to read temperator from sensor","humidity":"Failed to read humidity from sensor","isScheduleMode":0,"ssid":"rato","pass":"imakestuff","isScheduled":0},"relays":[{"name":"Fruit Tree","pin":27,"isRunning":1,"isEnabled":1,"times":[{"startTime":"11:01","duration":40,"hour":11,"min":1}]},{"name":"Vegie Garden","pin":26,"isRunning":1,"isEnabled":1,"status":1,"times":[{"startTime":"11:02","duration":49,"hour":11,"min":2}]},{"name":"Cypress Hill","pin":25,"isRunning":1,"isEnabled":0,"status":1,"times":[{"startTime":"03:03","duration":60,"hour":3,"min":3},{"startTime":"03:03","duration":60,"hour":3,"min":3}]}]}
read file - COMPLETE
json deserialize test - BEGIN
Connecting to WiFi..

lpgn, 2020-06-27:
I were able to reproduce the problem with good repeatability here are the steps:

1. burn firmware;
2. burn spiffs image;
3. parse initial jason with /updateData;
4. esp32 login to WiFi and all works well so far;
5. disconnect power of board (board loses time);
6. connect to the board thru SoftAP and access thru softAP IP 192.168.4.1;
7. page starts loading stops half way, watchdog intervenes and reboot board with message above;
8. enable the wifi, board connects to wifi (gets internet time) and network IP;
9. page continues loading and problem disappears.

- Probable solutions:
I will try to get time from battery powered rtc clock;

Kashyapkoshti, 2020-08-28:
rst:0x10 (RTCWDT_RTC_RESET),boot:0x1f (SPI_FAST_FLASH_BOOT)
flash read err, 1000
ets_main.c 371

I am getting this error in my esp32 devkit v1
How to solve it?

lpgn, 2020-11-19:
@Kashyapkoshti can you give more details are you trying to implement this project in to a esp32?

Kashyapkoshti, 2020-11-19:
@lpgn  i am using DOIT devkit v1 Esp32 for making remote controlled car with wifi

lpgn, 2021-05-10:
I believe it was solved removing delays

Closed 2021-05-10.

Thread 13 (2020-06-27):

wi-fi ssid and password parsed with json

lpgn, 2020-06-27:
To have a way of changing the wi-fi ssid and password without burning again the firmware is a must. The current problem for this easy implementation is that in first time boot, after a upload of spiffs image there is no Json and thus no way to go into the page and parse the first Json...

lpgn, 2022-03-11:
that first problem is solved with the function implemented some time ago to create a new json file when none is present.

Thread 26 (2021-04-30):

corrupt JSON file

lpgn, 2021-04-30:
after refresh p[age does not rebuild.
We believe its due to hardware and will build another test board to confirm.

jknight, 2021-04-30:
💻 🔥

lpgn, 2021-05-10:
solved 234f2fd

Closed 2021-05-10.

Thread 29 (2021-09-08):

implement pump current feedback

lpgn, 2021-09-08:
By using the current sensor we should be able to obtain feedback if either the pump is running dry or stuck

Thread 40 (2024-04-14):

DHT sensor causing Guru Meditation Error

lpgn, 2024-04-14:
Guru Meditation Error: Core  1 panic'ed (Interrupt wdt timeout on CPU1).

Core  1 register dump:
PC      : 0x400d7d20  PS      : 0x00060135  A0      : 0x800d7df8  A1      : 0x3ffd41b0
A2      : 0x00022165  A3      : 0x00000001  A4      : 0x3ffc4978  A5      : 0xdacae800
A6      : 0x00000000  A7      : 0x40404040  A8      : 0x00027100  A9      : 0x00022165
A10     : 0x00000001  A11     : 0x00000000  A12     : 0x00000000  A13     : 0x00200000
A14     : 0x00000028  A15     : 0x00000001  SAR     : 0x00000015  EXCCAUSE: 0x00000006
EXCVADDR: 0x00000000  LBEG    : 0x40084a05  LEND    : 0x40084a0d  LCOUNT  : 0x00000027

Backtrace: 0x400d7d1d:0x3ffd41b0 0x400d7df5:0x3ffd41d0 0x400d7e85:0x3ffd4330 0x400d43a2:0x3ffd4360 0x400d43f9:0x3ffd4390 0x400d6d72:0x3ffd43b0 0x4018ec67:0x3ffd4430 0x400df475:0x3ffd4450 0x400dd029:0x3ffd44a0 0x400dd139:0x3ffd44f0 0x400dd321:0x3ffd4540 0x4017434d:0x3ffd4560 0x401743c9:0x3ffd4590 0x40174bae:0x3ffd4�

By disabling temperature and humidity read error disappears.

lpgn, 2024-04-14:
addr2line -e .pio/build/esp32doit
-devkit-v1/firmware.elf -a -f 0x400d7d1d:0x3ffd41b0 0x400d7df5:0x3ffd41d0 0x400d7e85:0x3ffd4330 0x400d43a2:0x3ffd4360 0x400d43f9:0x3ffd4390 0x400d6d72:0x3ffd43b0 0x4018ec67:0x3ffd4430 0x400df475:0x3ffd4450 0x400dd029:0x3ffd44a0 0x400dd139:0x3ffd44f0 0x400dd321:0x3ffd4540 0x4017434d:0x3ffd4560 0x401743c9:0x3ffd4590 0x40174bae:0x3ffd4
0x400d7d1d
_ZN3DHT11expectPulseEb
/home/lpgn/gits_go_here_wsl/E-SPlash/Firmware/.pio/libdeps/esp32doit-devkit-v1/DHT sensor library/DHT.cpp:388
0x400d7df5
_ZN3DHT4readEb
/home/lpgn/gits_go_here_wsl/E-SPlash/Firmware/.pio/libdeps/esp32doit-devkit-v1/DHT sensor library/DHT.cpp:306
0x400d7e85
_ZN3DHT15readTemperatureEbb
/home/lpgn/gits_go_here_wsl/E-SPlash/Firmware/.pio/libdeps/esp32doit-devkit-v1/DHT sensor library/DHT.cpp:88
0x400d43a2
_Z11readDHTDatab
/home/lpgn/gits_go_here_wsl/E-SPlash/Firmware/src/fabfarm_irrigation/SetupSensors.cpp:22
0x400d43f9
_Z18readDHTTemperaturev
/home/lpgn/gits_go_here_wsl/E-SPlash/Firmware/src/fabfarm_irrigation/SetupSensors.cpp:44
0x400d6d72
_Z24handleGetDataJsonRequestP21AsyncWebServerRequest
/home/lpgn/gits_go_here_wsl/E-SPlash/Firmware/src/fabfarm_irrigation/WebServerManager.cpp:24
0x4018ec67
_ZNSt17_Function_handlerIFvP21AsyncWebServerRequestEPS2_E9_M_invokeERKSt9_Any_dataOS1_
/home/lpgn/.platformio/packages/toolchain-xtensa-esp32/xtensa-esp32-elf/include/c++/8.4.0/bits/std_function.h:297
0x400df475
_ZNKSt8functionIFvP21AsyncWebServerRequestEEclES1_
/home/lpgn/.platformio/packages/toolchain-xtensa-esp32/xtensa-esp32-elf/include/c++/8.4.0/bits/std_function.h:687
0x400dd029
_ZN21AsyncWebServerRequest10_parseLineEv
/home/lpgn/gits_go_here_wsl/E-SPlash/Firmware/.pio/libdeps/esp32doit-devkit-v1/ESP Async WebServer/src/WebRequest.cpp:581 (discriminator 1)
0x400dd139
_ZN21AsyncWebServerRequest7_onDataEPvj
/home/lpgn/gits_go_here_wsl/E-SPlash/Firmware/.pio/libdeps/esp32doit-devkit-v1/ESP Async WebServer/src/WebRequest.cpp:123
0x400dd321
_ZNSt17_Function_handlerIFvPvP11AsyncClientS0_jEZN21AsyncWebServerRequestC4EP14AsyncWebServerS2_EUlS0_S2_S0_jE6_E9_M_invokeERKSt9_Any_dataOS0_OS2_SC_Oj
/home/lpgn/gits_go_here_wsl/E-SPlash/Firmware/.pio/libdeps/esp32doit-devkit-v1/ESP Async WebServer/src/WebRequest.cpp:76
0x4017434d
_ZNKSt8functionIFvPvP11AsyncClientS0_jEEclES0_S2_S0_j
/home/lpgn/.platformio/packages/toolchain-xtensa-esp32/xtensa-esp32-elf/include/c++/8.4.0/bits/std_function.h:687
0x401743c9
_ZN11AsyncClient7_s_recvEPvP7tcp_pcbP4pbufa
/home/lpgn/gits_go_here_wsl/E-SPlash/Firmware/.pio/libdeps/esp32doit-devkit-v1/AsyncTCP/src/AsyncTCP.cpp:1191
0x40174bae
_ZL19_async_service_taskPv
/home/lpgn/gits_go_here_wsl/E-SPlash/Firmware/.pio/libdeps/esp32doit-devkit-v1/AsyncTCP/src/AsyncTCP.cpp:159

WingCode, 2024-04-15:
Might be related to https://github.com/adafruit/DHT-sensor-library/issues/211

Closed 2024-04-16.

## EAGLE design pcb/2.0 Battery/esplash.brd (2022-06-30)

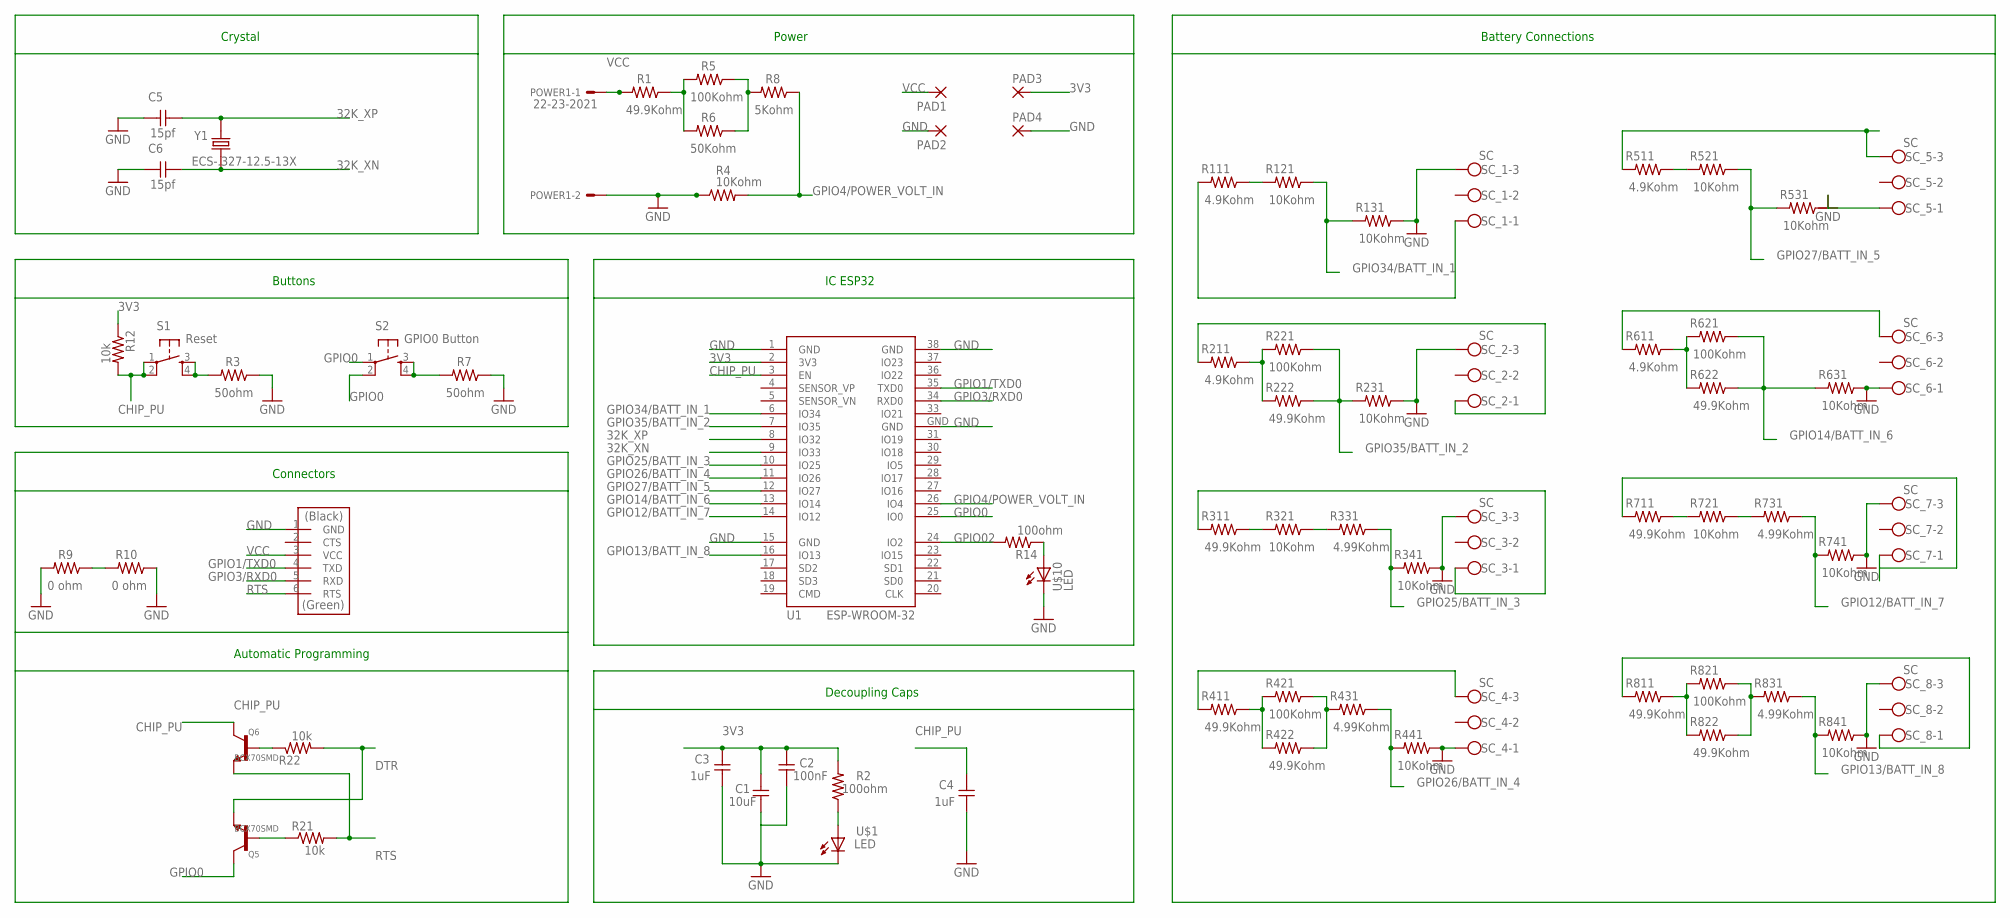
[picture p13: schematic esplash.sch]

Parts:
C1: 10uF; C1206FAB
C2: 100nF; C1206FAB
C3, C4: 1uF; C1206FAB
C5, C6: 15pf; C1206FAB
PAD1, PAD2, PAD3, PAD4: 2,15/1,0
POWER1: 22-23-2021
Q5, Q6: BCX70SMD; SOT23
R1, R222, R311, R411, R422, R622, R711, R811, R822: 49.9Kohm; R1206FAB
R2, R14: 100ohm; R1206
R3, R7: 50ohm; R1206FAB
R4, R121, R131, R231, R321, R341, R441, R521, R531, R631, R721, R741, R841: 10Kohm; R1206FAB
R5, R221, R421, R621, R821: 100Kohm; R1206FAB
R6: 50Kohm; R1206FAB
R8: 5Kohm; R1206FAB
R9, R10: 0 ohm; R1206FAB
R12, R21, R22: 10k; R1206
R111, R211, R511, R611: 4.9Kohm; R1206FAB
R331, R431, R731, R831: 4.99Kohm; R1206FAB
RTS: FTDI-SMD-HEADER; 1X06SMD
S1: Reset; 6MM_SWITCH
S2: GPIO0 Button; 6MM_SWITCH
SC_1, SC_2, SC_3, SC_4, SC_5, SC_6, SC_7, SC_8: SC; W237-103
U1: ESP-WROOM-32
U$1, U$10: LED; LED1206
Y1: ECS-.327-12.5-13X; XTAL_ECS-.327-12.5-13X

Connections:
3V3: C1.2, C2.1, C3.1, PAD3.1, R2.2, R12.1, U1.2 (3V3)
32K_XN: C6.2, U1.9 (IO33), Y1.1
32K_XP: C5.2, U1.8 (IO32), Y1.2
CHIP_PU: C4.1, Q6.3 (C), R12.2, S1.1, S1.2 (P1), U1.3 (EN)
DTR: Q5.2 (E), R22.2
GND: C1.1, C2.2, C3.2, C4.2, C5.1, C6.1, PAD2.1, PAD4.1, POWER1.2, R3.1, R4.1, R7.1, R9.2, R10.1, R131.1, R231.1, R341.1, R441.1, R531.1, R631.1, R741.1, R841.1, RTS.1 (GND), SC_1.3, SC_2.3, SC_3.3, SC_4.1, SC_5.1, SC_6.1, SC_7.3, SC_8.3, U1.1 (GND), U1.15 (GND), U1.38 (GND), U1.GND, U$1.2 (C), U$10.2 (C)
GPIO0: Q5.3 (C), S2.1, S2.2 (P1), U1.25 (IO0)
GPIO1/TXD0: RTS.4 (TXD), U1.35 (TXD0)
GPIO02: R14.2, U1.24 (IO2)
GPIO3/RXD0: RTS.5 (RXD), U1.34 (RXD0)
GPIO4/POWER_VOLT_IN: R4.2, R8.1, U1.26 (IO4)
GPIO12/BATT_IN_7: R731.1, R741.2, U1.14 (IO12)
GPIO13/BATT_IN_8: R831.1, R841.2, U1.16 (IO13)
GPIO14/BATT_IN_6: R621.1, R622.1, R631.2, U1.13 (IO14)
GPIO25/BATT_IN_3: R331.1, R341.2, U1.10 (IO25)
GPIO26/BATT_IN_4: R431.1, R441.2, U1.11 (IO26)
GPIO27/BATT_IN_5: R521.1, R531.2, U1.12 (IO27)
GPIO34/BATT_IN_1: R121.1, R131.2, U1.6 (IO34)
GPIO35/BATT_IN_2: R221.1, R222.1, R231.2, U1.7 (IO35)
unnamed: R1.1, R5.2, R6.2
unnamed: R3.2, S1.3 (S), S1.4 (S1)
unnamed: R111.1, R121.2
unnamed: R14.1, U$10.1 (A)
unnamed: R111.2, SC_1.1
unnamed: R5.1, R6.1, R8.2
unnamed: R211.2, SC_2.1
unnamed: R611.2, SC_6.3
unnamed: R9.1, R10.2
unnamed: R2.1, U$1.1 (A)
unnamed: R211.1, R221.2, R222.2
unnamed: R7.2, S2.3 (S), S2.4 (S1)
unnamed: R311.2, SC_3.1
unnamed: R311.1, R321.2
unnamed: Q5.1 (B), R21.1
unnamed: R321.1, R331.2
unnamed: R411.2, SC_4.3
unnamed: R411.1, R421.2, R422.2
unnamed: Q6.1 (B), R22.1
unnamed: R421.1, R422.1, R431.2
unnamed: R511.1, R521.2
unnamed: R511.2, SC_5.3
unnamed: R611.1, R621.2, R622.2
unnamed: R711.2, SC_7.1
unnamed: R711.1, R721.2
unnamed: R721.1, R731.2
unnamed: R811.2, SC_8.1
unnamed: R811.1, R821.2, R822.2
unnamed: R821.1, R822.1, R831.2
RTS: Q6.2 (E), R21.2, RTS.6 (RTS)
VCC: PAD1.1, POWER1.1, R1.2, RTS.3 (VCC)

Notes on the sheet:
Power
IC ESP32
Crystal
Buttons
Connectors
Battery Connections
Automatic Programming
Decoupling Caps

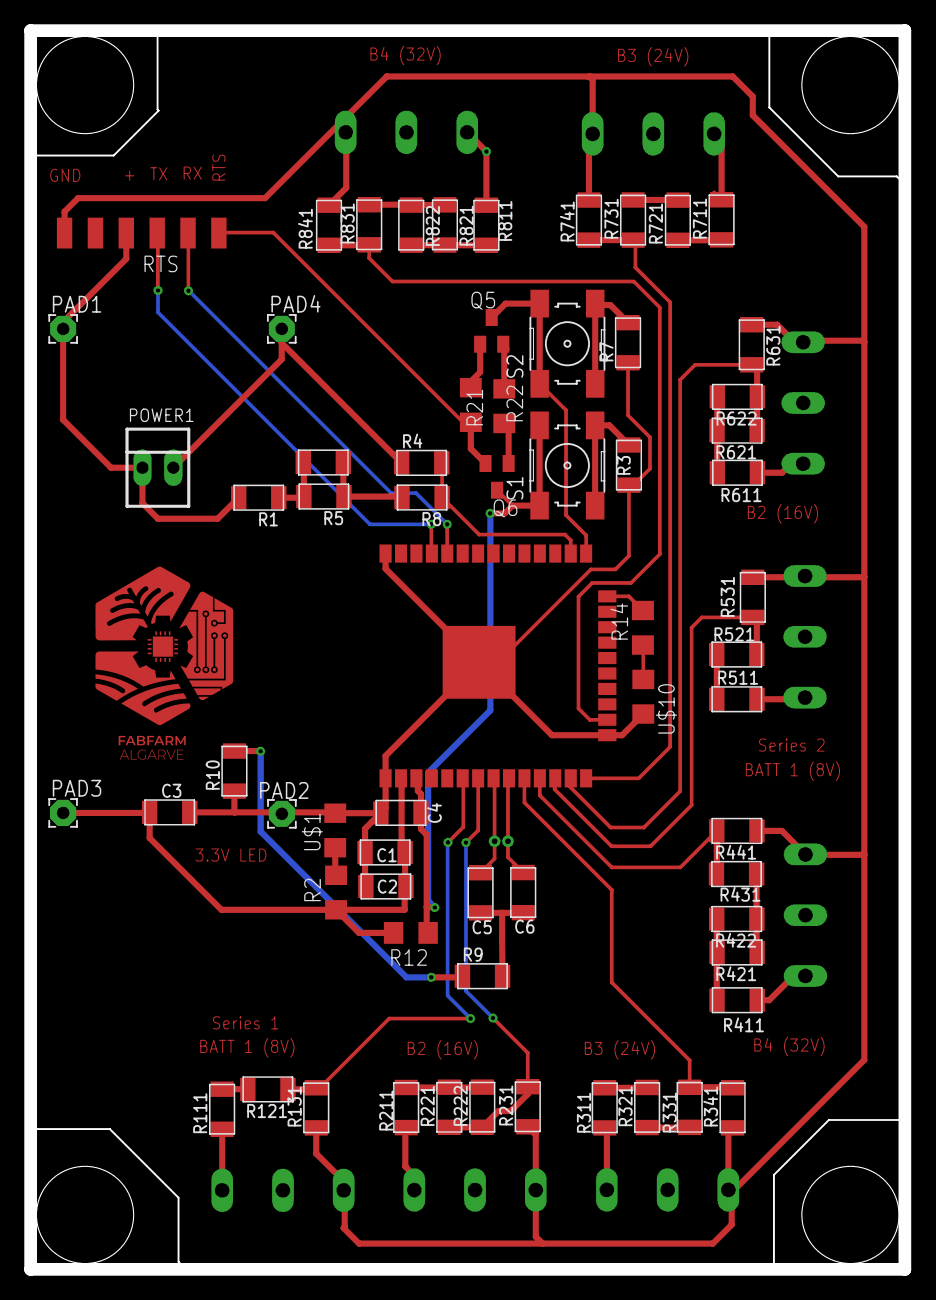
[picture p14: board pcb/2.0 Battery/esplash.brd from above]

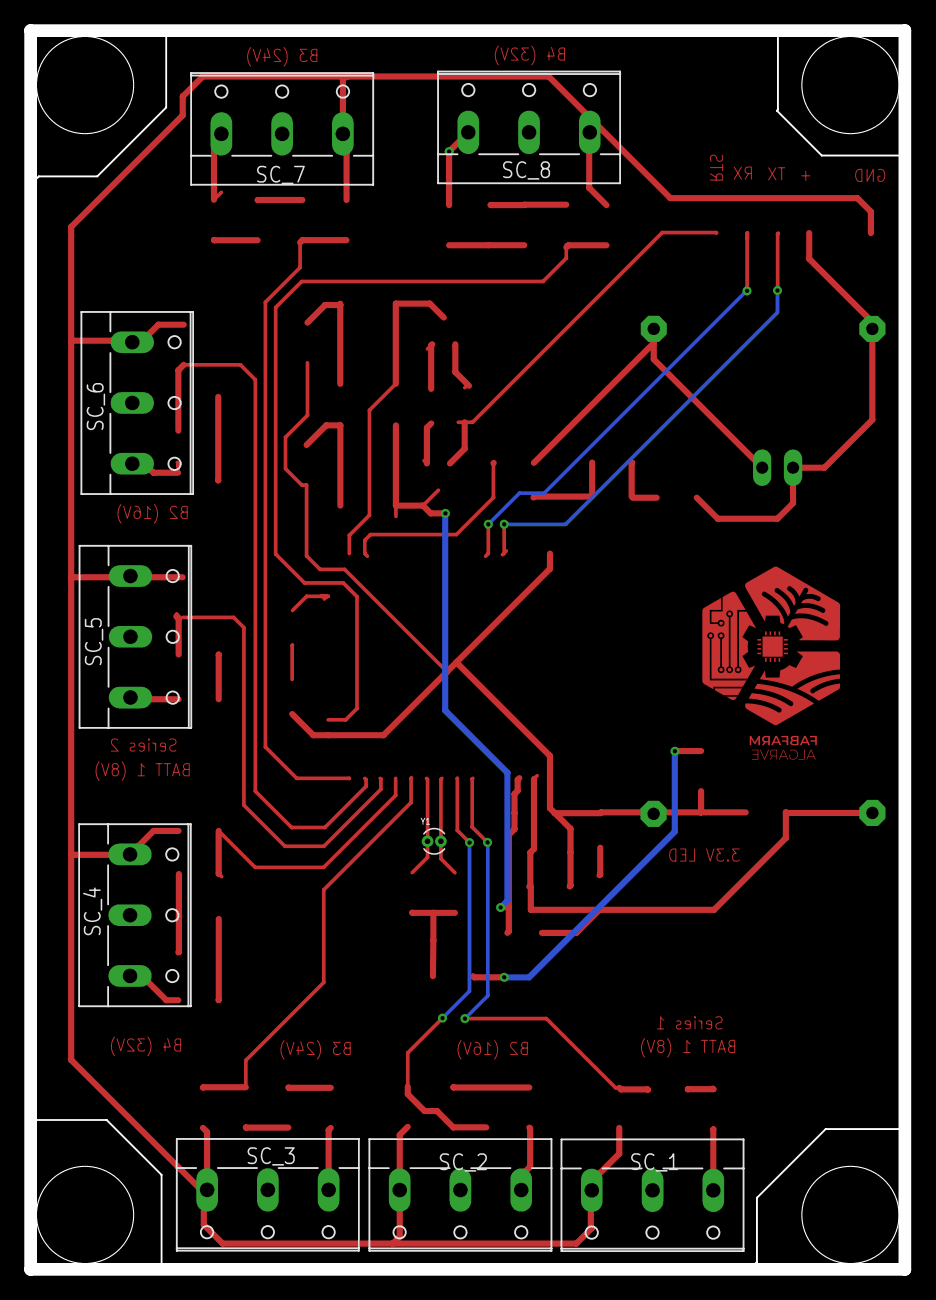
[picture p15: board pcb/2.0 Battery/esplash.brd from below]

Board: 2 copper layers, 72.0 x 102.0 mm, 74 parts (9 on the bottom side), 50 nets.

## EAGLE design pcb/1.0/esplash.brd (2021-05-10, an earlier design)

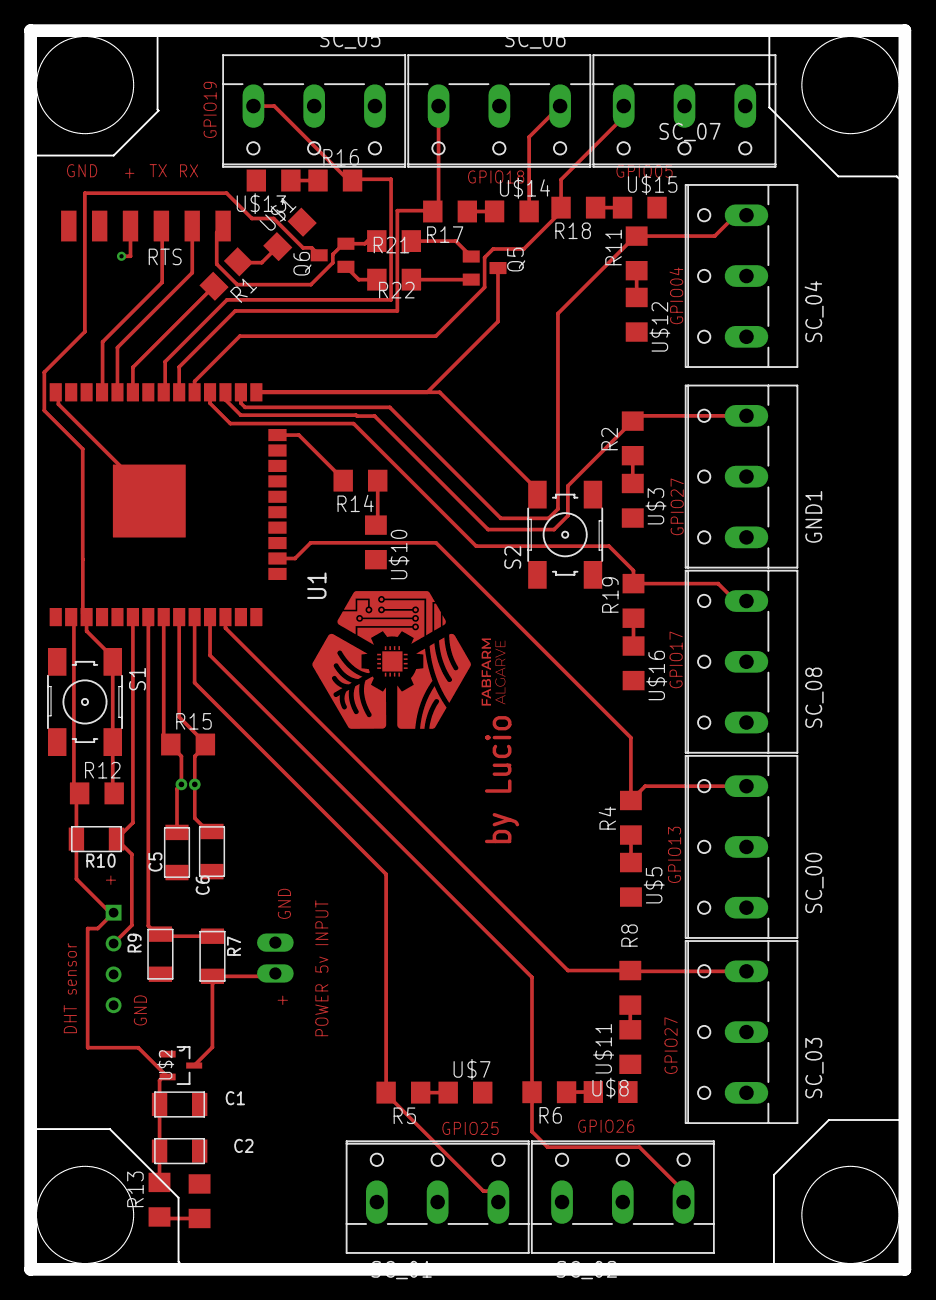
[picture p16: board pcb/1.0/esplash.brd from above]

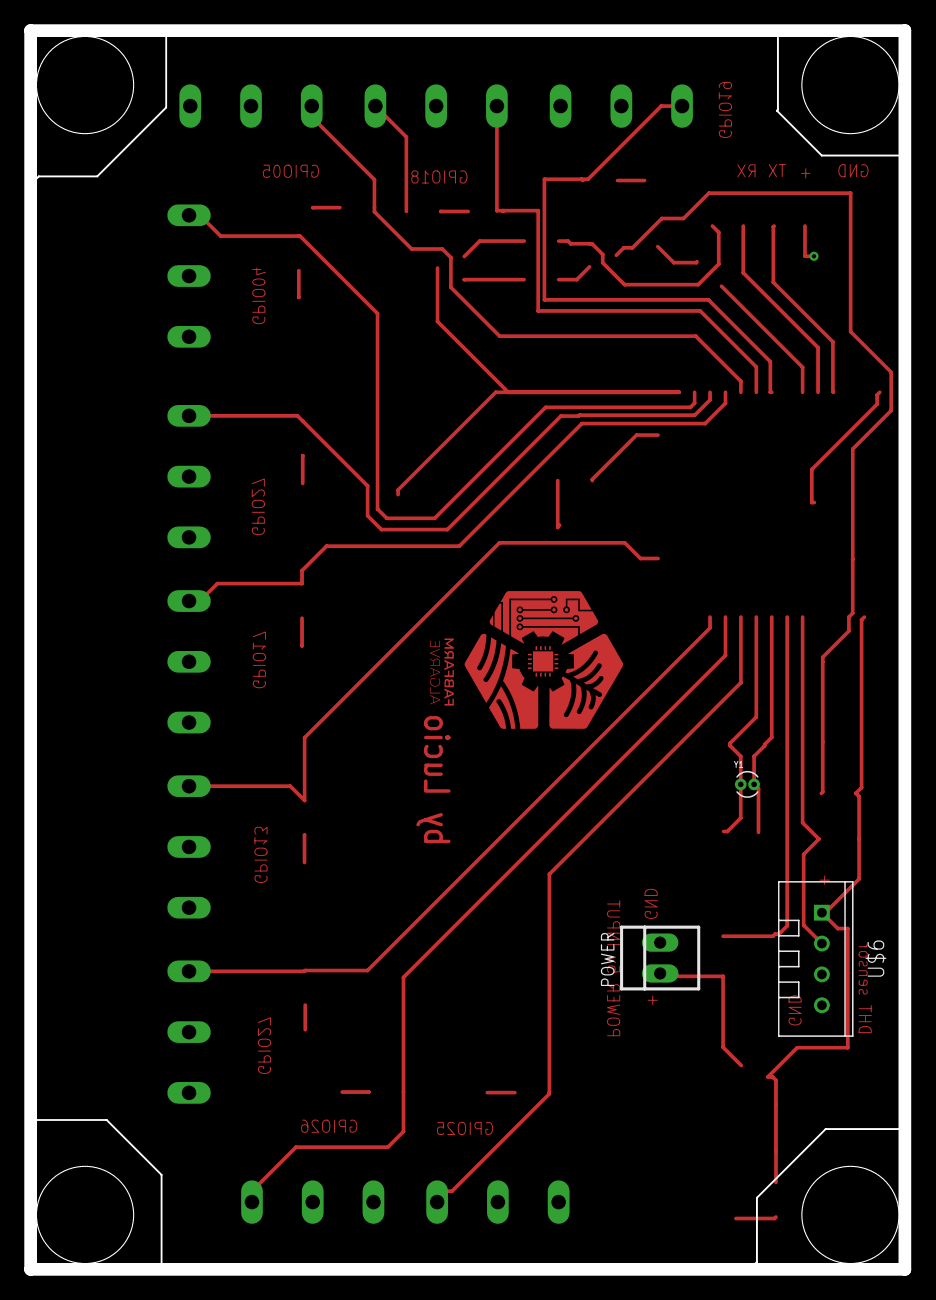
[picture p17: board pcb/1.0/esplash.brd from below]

Board: 2 copper layers, 72.0 x 102.0 mm, 57 parts (3 on the bottom side), 40 nets.

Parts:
C1: 100nF; C1206FAB
C2: 100uF; C1206FAB
C5, C6: 15pf; C1206FAB
GND1: SC; W237-103
POWER: 22-23-2021
Q5, Q6: BCX70SMD; SOT23
R1, R2, R4, R5, R6, R8, R11, R13, R14, R16, R17, R18, R19: 100ohm; R1206
R7: 1.2Mohm; R1206FAB
R9: 1.5Mohm; R1206FAB
R10: 10K; R1206FAB
R12, R15, R21, R22: 10k; R1206
RTS: FTDI-SMD-HEADER; 1X06SMD
S1: Reset; 6MM_SWITCH
S2: GPIO0 Button; 6MM_SWITCH
SC_00, SC_01, SC_02, SC_03, SC_04, SC_05, SC_06, SC_07, SC_08: SC; W237-103
U1: ESP-WROOM-32
U$1, U$3, U$5, U$7, U$8, U$9, U$10, U$11, U$12, U$13, U$14, U$15, U$16: LED; LED1206
U$2: MCP1700T-3302E/TT; SOT95P237X112-3N
U$6: TEMP-HUM-SENSOR-DHT11
Y1: ECS-.327-12.5-13X; XTAL_ECS-.327-12.5-13X

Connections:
3V3: C1.2, C2.1, R10.2, R12.1, R13.2, U1.2, U$2.2, U$6.1
32K_XN: C6.2, R15.2, U1.9, Y1.1
32K_XP: C5.2, R15.1, U1.8, Y1.2
CHIP_PU: Q6.3, R12.2, S1.1, S1.2, U1.3
DTR: Q5.2, R22.2
GND: C1.1, C2.2, C5.1, C6.1, GND1.1, POWER.2, R9.1, RTS.1, S1.3, S1.4, S2.3, S2.4, SC_00.1, SC_01.1, SC_02.1, SC_03.1, SC_04.1, SC_05.1, SC_06.1, SC_07.1, SC_08.1, U1.1, U1.15, U1.38, U1.GND, U$1.2, U$2.1, U$3.2, U$5.2, U$6.4, U$7.2, U$8.2, U$9.2, U$10.2, U$11.2, U$12.2, U$13.2, U$14.2, U$15.2, U$16.2
GPIO0: Q5.3, S2.1, S2.2, U1.25
GPIO1/TXD0: RTS.4, U1.35
GPIO02: R14.2, U1.24
GPIO3/RXD0: RTS.5, U1.34
GPIO4: R11.2, SC_04.3, U1.26
GPIO05/VALVE_RELAY07: R18.2, SC_07.3, U1.29
GPIO13/PUMP_RELAY: R4.2, SC_00.3, U1.16
GPIO16/CURRENT_SENSE: GND1.3, R2.2, U1.27
GPIO17/VALVE_RELAY08: R19.2, SC_08.3, U1.28
GPIO18/VALVE_RELAY06: R17.2, SC_06.3, U1.30
GPIO19/VALVE_RELAY05: R16.2, SC_05.3, U1.31
GPIO21/VALVE_RELAY04: R1.2, U1.33
GPIO25/VALVE_RELAY01: R5.2, SC_01.3, U1.10
GPIO26/VALVE_RELAY02: R6.2, SC_02.3, U1.11
GPIO27/VALVE_RELAY03: R8.2, SC_03.3, U1.12
GPIO34/DHT: R10.1, U1.6, U$6.2
GPIO35/BATTVOLT: R7.1, R9.2, U1.7
unnamed: R1.1, U$1.1
unnamed: R2.1, U$3.1
unnamed: R14.1, U$10.1
unnamed: R4.1, U$5.1
unnamed: R5.1, U$7.1
unnamed: R6.1, U$8.1
unnamed: R8.1, U$11.1
unnamed: R11.1, U$12.1
unnamed: R16.1, U$13.1
unnamed: R13.1, U$9.1
unnamed: Q5.1, R21.1
unnamed: R17.1, U$14.1
unnamed: R18.1, U$15.1
unnamed: R19.1, U$16.1
unnamed: Q6.1, R22.1
RTS: Q6.2, R21.2, RTS.6
VCC: GND1.2, POWER.1, R7.2, RTS.3, SC_00.2, SC_01.2, SC_02.2, SC_03.2, SC_04.2, SC_05.2, SC_06.2, SC_07.2, SC_08.2, U$2.3

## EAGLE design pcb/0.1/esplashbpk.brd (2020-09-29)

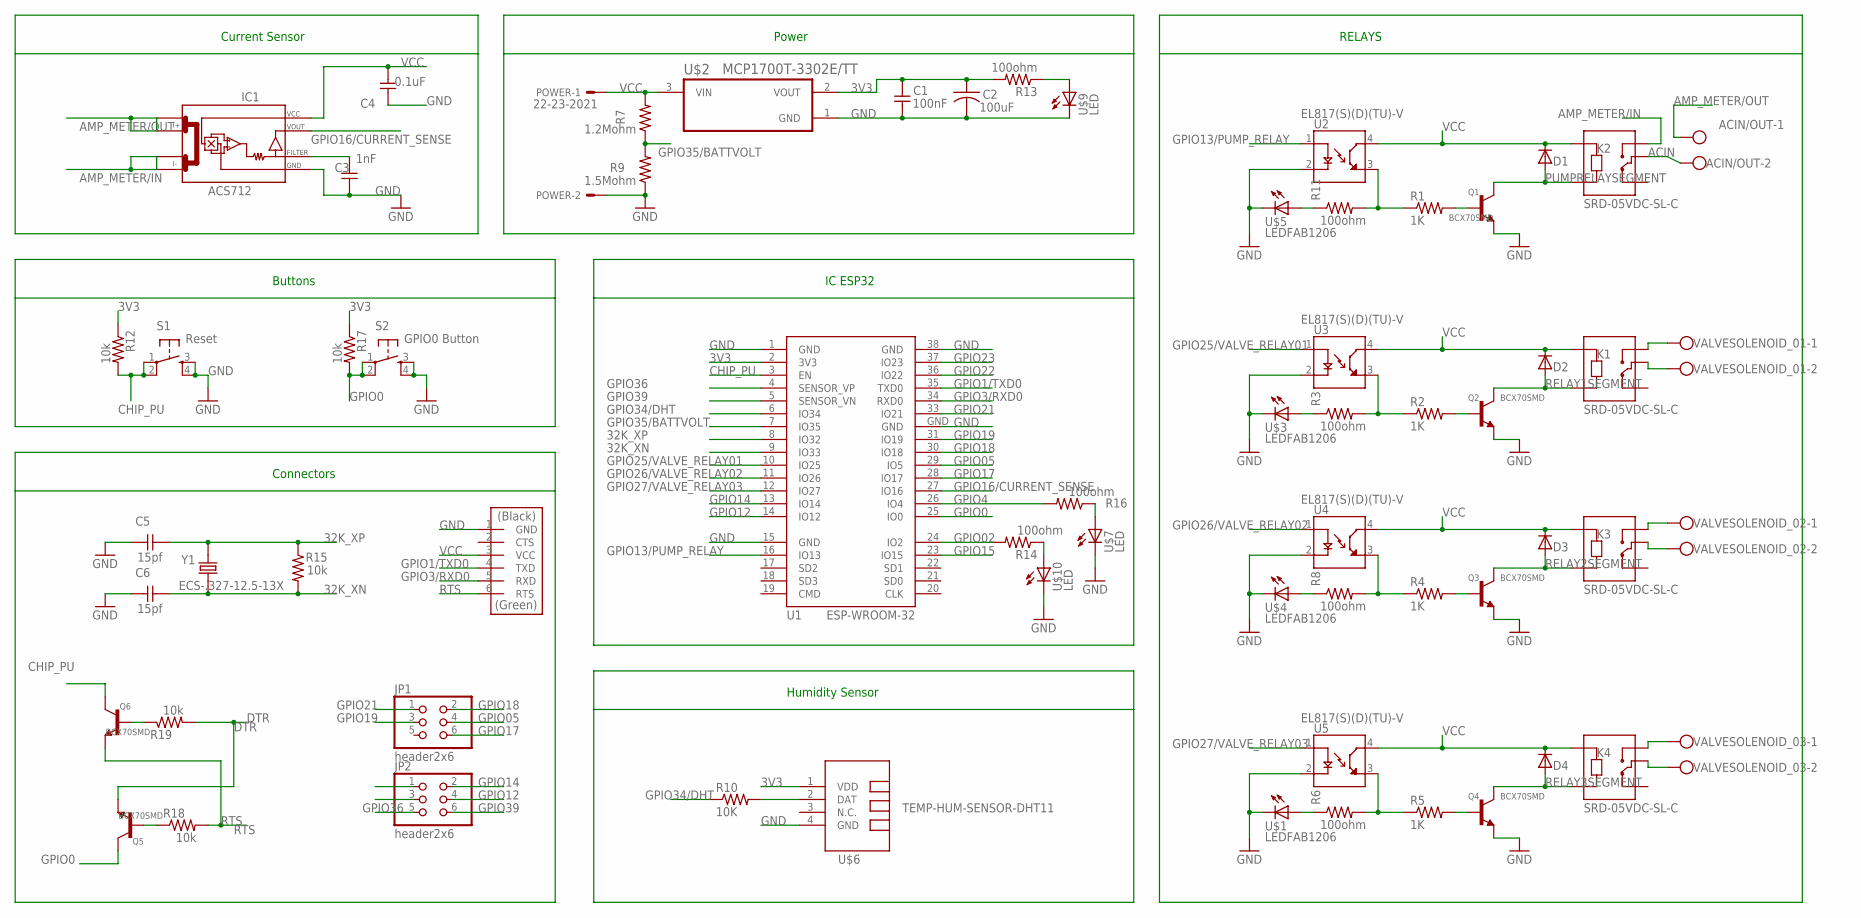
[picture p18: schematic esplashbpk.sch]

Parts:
ACIN/OUT: W237-102
C1: 100nF; C1206FAB
C2: 100uF; C1206FAB
C3: 1nF; C1206FAB
C4: 0.1uF; C1206FAB
C5, C6: 15pf; C1206FAB
D1, D2, D3, D4: DIODESOD123; SOD123
IC1: ACS712; SO08
JP1, JP2: header2x6; 2X03
K1, K2, K3, K4: SRD-05VDC-SL-C; RELAY_SRD-05VDC-SL-C
POWER: 22-23-2021
Q1, Q2, Q3, Q4, Q5, Q6: BCX70SMD; SOT23
R1, R2, R4, R5: 1K; R1206FAB
R3, R6, R8, R11: 100ohm; R1206FAB
R7: 1.2Mohm; R1206FAB
R9: 1.5Mohm; R1206FAB
R10: 10K; R1206FAB
R12, R15, R17, R18, R19: 10k; R1206
R13, R14, R16: 100ohm; R1206
RTS: FTDI-SMD-HEADER; 1X06SMD
S1: Reset; 6MM_SWITCH
S2: GPIO0 Button; 6MM_SWITCH
U1: ESP-WROOM-32
U2, U3, U4, U5: EL817(S)(D)(TU)-V; SOIC254P1030X460-4N
U$1, U$3, U$4, U$5: LEDFAB1206; LED1206FAB
U$2: MCP1700T-3302E/TT; SOT95P237X112-3N
U$6: TEMP-HUM-SENSOR-DHT11
U$7, U$9, U$10: LED; LED1206
VALVESOLENOID_01, VALVESOLENOID_02, VALVESOLENOID_03: W237-102
Y1: ECS-.327-12.5-13X; XTAL_ECS-.327-12.5-13X

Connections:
3V3: C1.2, C2.1, R12.1, R13.2, R17.1, U1.2 (3V3), U$2.2 (VOUT), U$6.1 (VDD)
32K_XN: C6.2, R15.2, U1.9 (IO33), Y1.1
32K_XP: C5.2, R15.1, U1.8 (IO32), Y1.2
ACIN: ACIN/OUT.2, K2.COM
AMP_METER/IN: IC1.3 (I-_0), IC1.4 (I-_1), K2.NO
AMP_METER/OUT: ACIN/OUT.1, IC1.1 (I+_0), IC1.2 (I+_1)
CHIP_PU: Q6.3 (C), R12.2, S1.1, S1.2 (P1), U1.3 (EN)
DELETE: C3.2, IC1.6 (FILTER)
DTR: Q5.2 (E), R19.2
GND: C1.1, C2.2, C3.1, C4.1, C5.1, C6.1, IC1.5 (GND), POWER.2, Q1.2 (E), Q2.2 (E), Q3.2 (E), Q4.2 (E), R9.1, RTS.1 (GND), S1.3 (S), S1.4 (S1), S2.3 (S), S2.4 (S1), U1.1 (GND), U1.15 (GND), U1.38 (GND), U1.GND, U2.2 (C), U3.2 (C), U4.2 (C), U5.2 (C), U$1.2 (C), U$2.1 (GND), U$3.2 (C), U$4.2 (C), U$5.2 (C), U$6.4 (GND), U$7.2 (C), U$9.2 (C), U$10.2 (C)
GPIO0: Q5.3 (C), R17.2, S2.1, S2.2 (P1), U1.25 (IO0)
GPIO1/TXD0: RTS.4 (TXD), U1.35 (TXD0)
GPIO02: R14.2, U1.24 (IO2)
GPIO3/RXD0: RTS.5 (RXD), U1.34 (RXD0)
GPIO4: R16.2, U1.26 (IO4)
GPIO05: JP1.4, U1.29 (IO5)
GPIO12: JP2.4, U1.14 (IO12)
GPIO13/PUMP_RELAY: U1.16 (IO13), U2.1 (A)
GPIO14: JP2.2, U1.13 (IO14)
GPIO15: U1.23 (IO15)
GPIO16/CURRENT_SENSE: IC1.7 (VOUT), U1.27 (IO16)
GPIO17: JP1.6, U1.28 (IO17)
GPIO18: JP1.2, U1.30 (IO18)
GPIO19: JP1.3, U1.31 (IO19)
GPIO21: JP1.1, U1.33 (IO21)
GPIO22: U1.36 (IO22)
GPIO23: U1.37 (IO23)
GPIO25/VALVE_RELAY01: U1.10 (IO25), U3.1 (A)
GPIO26/VALVE_RELAY02: U1.11 (IO26), U4.1 (A)
GPIO27/VALVE_RELAY03: U1.12 (IO27), U5.1 (A)
GPIO34/DHT: R10.1, U1.6 (IO34)
GPIO35/BATTVOLT: R7.1, R9.2, U1.7 (IO35)
GPIO36: JP2.5, U1.4 (SENSOR_VP)
GPIO39: JP2.6, U1.5 (SENSOR_VN)
unnamed: R1.1, R11.2, U2.3 (ET)
unnamed: K1.COM, VALVESOLENOID_01.2
unnamed: Q2.1 (B), R2.2
unnamed: R11.1, U$5.1 (A)
unnamed: R14.1, U$10.1 (A)
unnamed: K1.NO, VALVESOLENOID_01.1
unnamed: R3.1, U$3.1 (A)
unnamed: R2.1, R3.2, U3.3 (ET)
unnamed: K3.COM, VALVESOLENOID_02.2
unnamed: Q3.1 (B), R4.2
unnamed: R8.1, U$4.1 (A)
unnamed: R4.1, R8.2, U4.3 (ET)
unnamed: K3.NO, VALVESOLENOID_02.1
unnamed: K4.COM, VALVESOLENOID_03.2
unnamed: Q4.1 (B), R5.2
unnamed: R6.1, U$1.1 (A)
unnamed: R5.1, R6.2, U5.3 (ET)
unnamed: K4.NO, VALVESOLENOID_03.1
unnamed: R13.1, U$9.1 (A)
unnamed: R10.2, U$6.2 (DAT)
unnamed: R16.1, U$7.1 (A)
unnamed: Q5.1 (B), R18.1
unnamed: Q6.1 (B), R19.1
unnamed: Q1.1 (B), R1.2
PUMPRELAYSEGMENT: D1.ANODE (A), K2.A2, Q1.3 (C)
RELAY1SEGMENT: D2.ANODE (A), K1.A2, Q2.3 (C)
RELAY2SEGMENT: D3.ANODE (A), K3.A2, Q3.3 (C)
RELAY3SEGMENT: D4.ANODE (A), K4.A2, Q4.3 (C)
RTS: Q6.2 (E), R18.2, RTS.6 (RTS)
VCC: C4.2, D1.CATHODE (C), D2.CATHODE (C), D3.CATHODE (C), D4.CATHODE (C), IC1.8 (VCC), K1.A1, K2.A1, K3.A1, K4.A1, POWER.1, R7.2, RTS.3 (VCC), U2.4 (CT), U3.4 (CT), U4.4 (CT), U5.4 (CT), U$2.3 (VIN)

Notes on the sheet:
RELAYS
Power
IC ESP32
Humidity Sensor
Current Sensor
Buttons
Connectors

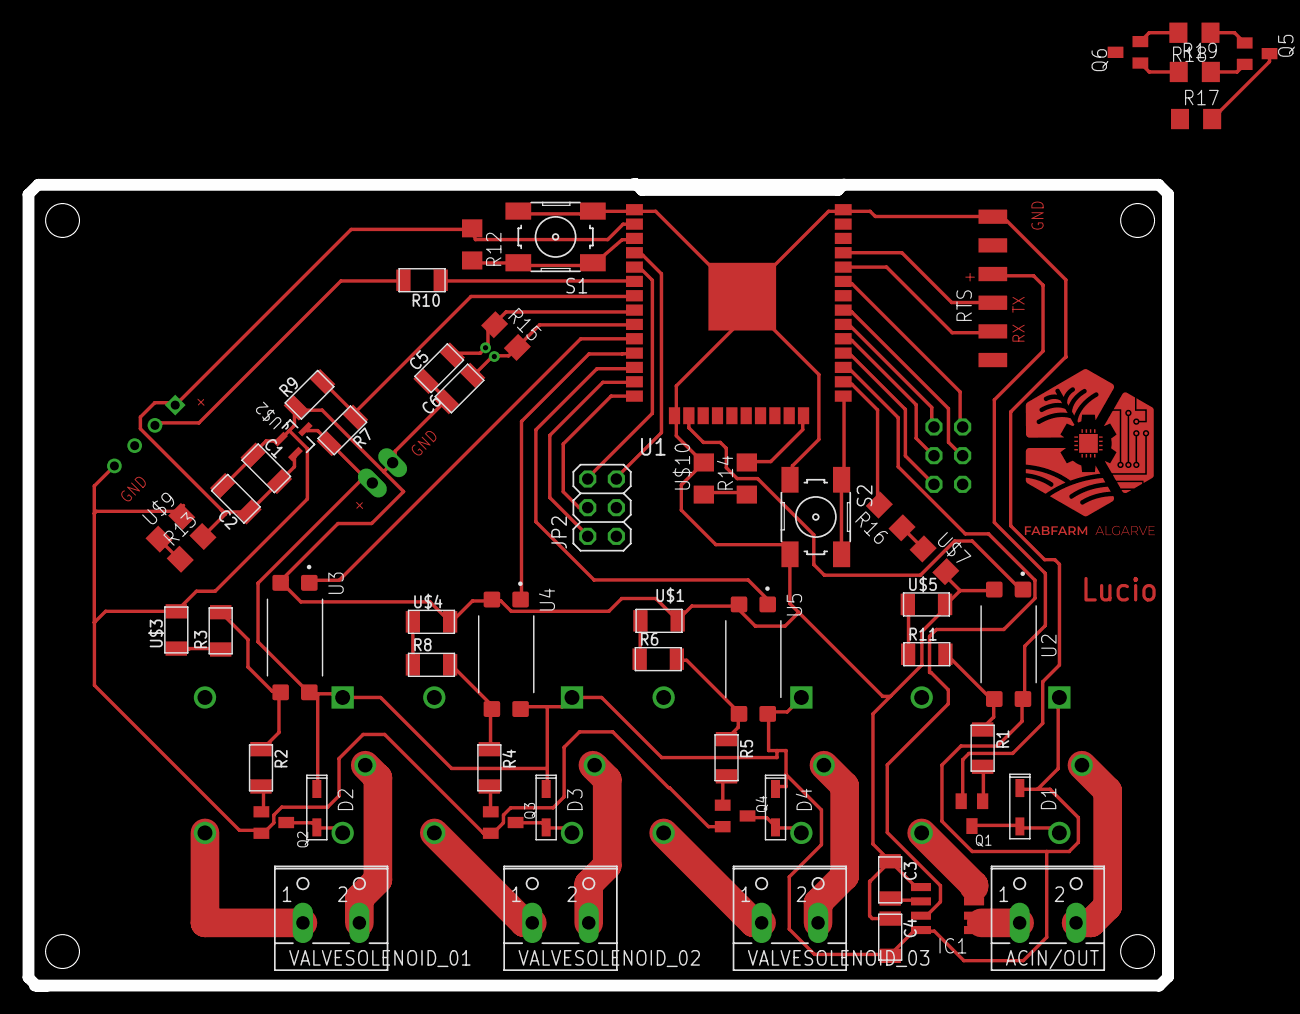
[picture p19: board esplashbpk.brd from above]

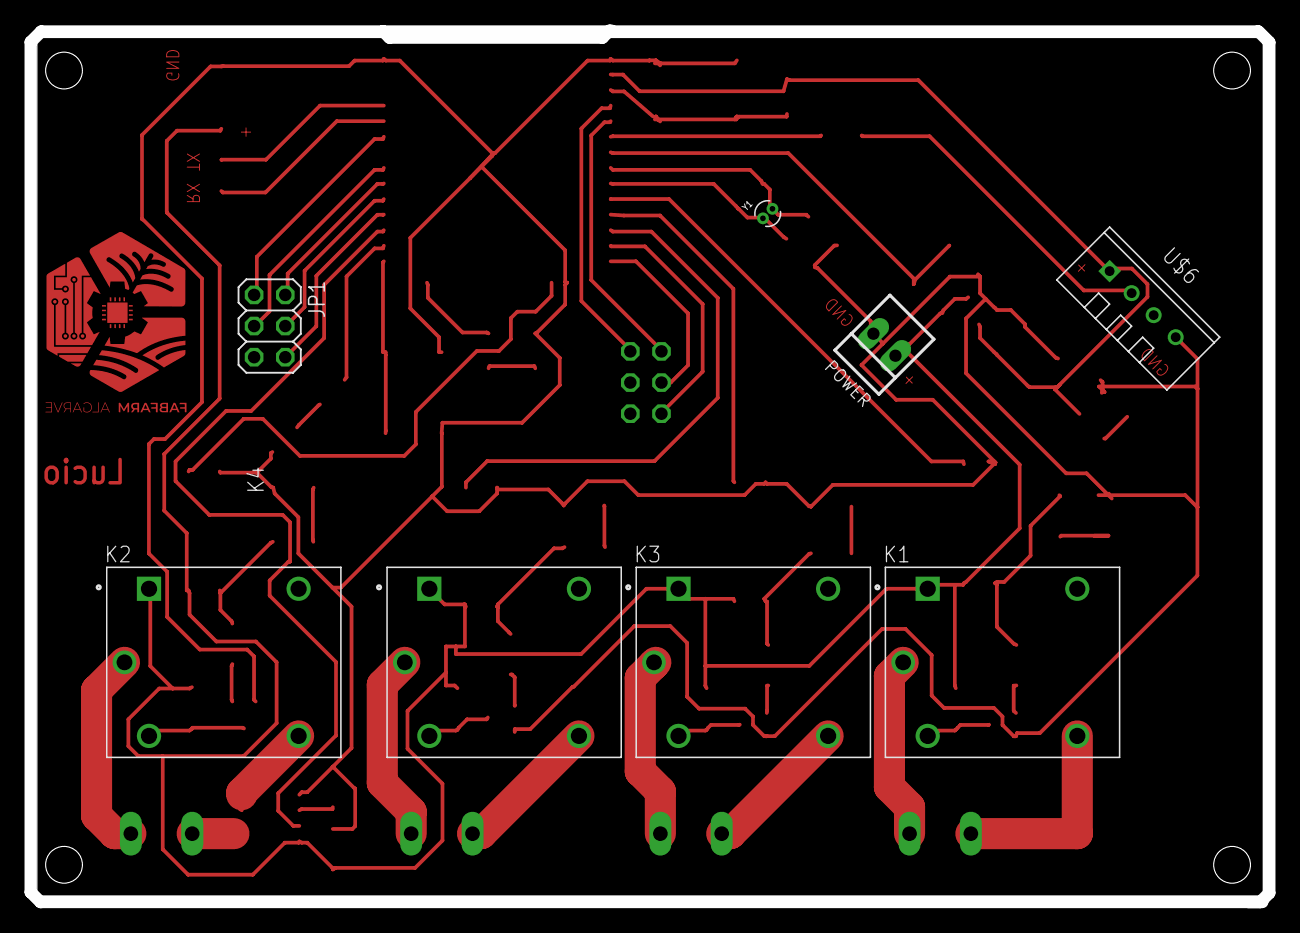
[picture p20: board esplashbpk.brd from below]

Board: 2 copper layers, 101.0 x 71.1 mm, 65 parts (8 on the bottom side), 61 nets.

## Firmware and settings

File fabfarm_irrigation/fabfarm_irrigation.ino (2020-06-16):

/****************************************************************************
 *                                  Aknowledments                           * 
 *                                  by LucioPGN                             * 
 ****************************************************************************/
/*  Up to this date: 07th of June 2020 I don't consider myself a programer 
 *  so I need to stand on top of giants sholders for my programing projects:
 *  A Portion of this code was based on Rui Santos Code; 
 *  Codes from Rui Santos mixed toghether:
 *  https://randomnerdtutorials.com/esp32-web-server-spiffs-spi-flash-file-system/
 *  https://randomnerdtutorials.com/esp32-relay-module-ac-web-server/
 *  https://randomnerdtutorials.com/esp32-date-time-ntp-client-server-arduino/
 *  From Techtutorialsx.com
 *  https://techtutorialsx.com/2017/12/01/esp32-arduino-asynchronous-http-webserver/
 *  A Portion of this code was based on Shakeels code for ESP8266 ;
 *  My contributions: 
 *     -So far I made it work on platformio :), that took me quite a lot of time
 *     -That means:
 *        +created a new project;
 *        +created a folder named data under the main folder (fabfarm_irrigation)
 *        +linked the platformio.ini to the folder of the project + the data folder
 *        +linked the needed libraries to their github repo in the platformio.ini
 *        +found a conflict with time library and A
 *  Things I still want to program for my final project:
 *    -so far I ported Shakeels code into ESP32;
 *    -separate functions from shakeels code into files;
 *    -separated functions from Rui Santos code into files.
 *    -simplify the code creating more functions;
 *    -try to separate the HTML part for a cleaner code;
 *    -Improve the appearance/Interface of the code
 *    -Add readings to HTML
 *    -Add a log of occurrences like over current
 *    -Add more safety for the equipment
 *    -Add a phone interface (APP)
 *    -Add function to set current time
 *    -Add renaming function to each relay so one can relate the relay to the area of interest or at least rename relays to actual areas of the farm.
 * 
 ****************************************************************************/
 

//Required Libraries
#include "WiFi.h"
#include "ESPAsyncWebServer.h"
#include "SPIFFS.h"
#include "AsyncTCP.h"
#include "Adafruit_Sensor.h"
#include "DHT.h"
#include "time.h"

const char* ntpServer = "pool.ntp.org";
const long  gmtOffset_sec = 0;
const int   daylightOffset_sec = 3600;

// Network Credentials
const char* ssid = "rato";
const char* password = "imakestuff";

//Start the Async Web Server listening on port 80
AsyncWebServer server(80);

// Set to true to define Relay as Normally Open (NO)
#define RELAY_NO false

// Set number of relays, will be used in the array
#define NUM_RELAYS  4

// Assign each GPIO to a relay
int relayGPIOs[NUM_RELAYS] = {26, 25, 33, 27};

// Digital pin connected to the DHT sensor
#define DHTPIN 32     

// Uncomment the type of sensor in use:
#define DHTTYPE    DHT11     // DHT 11
//#define DHTTYPE    DHT22     // DHT 22 (AM2302)
//#define DHTTYPE    DHT21     // DHT 21 (AM2301)

DHT dht(DHTPIN, DHTTYPE);

//
const char* PARAM_INPUT_1 = "relay";  
const char* PARAM_INPUT_2 = "state";

void setup(){
  // Serial port for debugging purposes
  Serial.begin(9600);

  // Initialize SPIFFS
  if(!SPIFFS.begin(true)){
    Serial.println("An Error has occurred while mounting SPIFFS");
    return;
  }
  // Set all relays to off when the program starts - if set to Normally Open (NO), the relay is off when you set the relay to HIGH
  for(int i=1; i<=NUM_RELAYS; i++){
    pinMode(relayGPIOs[i-1], OUTPUT);
    if(RELAY_NO){
      digitalWrite(relayGPIOs[i-1], HIGH);
    }
    else{
      digitalWrite(relayGPIOs[i-1], LOW);
    }
  }
  /*
  // Connect the ESP to the Wi-Fi using the credentials entered before
  //with WiFi.mode(WIFI_STA) besides the wifi client we will have a access point
  WiFi.mode(WIFI_AP_STA);// looks like this is not really needed, I need to investigate better how wifi works.
  //So far the behaviour is that it creates a soft access point and also connect to the network thru access point 
  //Here is how to start the soft access point :  WiFi.softAP("softap", "imakestuff");
  //This part of the code was taken from https://arduino-esp8266.readthedocs.io/en/latest/esp8266wifi/readme.html
  Serial.print("Setting soft-AP ... ");
  boolean result = WiFi.softAP("softap", "imakestuff");
  if(result == true)
  {
    Serial.println("Soft Access Point Started");
    IPAddress mySoftIP = WiFi.softAPIP();
    Serial.print("Soft Acess Point IP address: ");
    Serial.println(mySoftIP);
  }
  else
  {
    Serial.println("Soft Access Point Failed!");
  }
  */
  WiFi.softAP("softap", "imakestuff");
  IPAddress IP = WiFi.softAPIP();
  
  //here  start wifi sessions as a client.
  WiFi.begin(ssid, password);
  while (WiFi.status() != WL_CONNECTED) {
    delay(1000);
    Serial.println("Connecting to WiFi..");
  }

  // Print ESP32 Local IP Address
  Serial.print("The Fabfarm Irrigation system network IP is:");
  Serial.println(WiFi.localIP());
  //Serial.print("The gateway IP is:")
  //Serial.println(WiFi.gatewayIP());

  // Init and get the time from ntpServer
  configTime(gmtOffset_sec, daylightOffset_sec, ntpServer);
  //printFarmTime();
  //Serial.print("Now the Short Version: ");
  //printShortFarmTime();
  
  //Printing Only the hours and minutes
  Serial.print("Prepare for time...");
  modifiedPrintLocalTime();
  Serial.println("");

  //Print Only The hours
  Serial.print("Now prepare again to get more time...");
  Serial.print(gimeTime(1));
  Serial.print(":");
  Serial.println(gimeTime(2));

/*
*Now we are going to configure the route where server will be listening for incoming HTTP requests 
and a function that will be executed when a request is received on that route.
We specify this by calling the "on" method on the server object. With server.on(){}; 
As first input, this method receives a string with the path where it will be listening. 
We are going to set it to listen for requests on the “/” route. This could be anything. 
It is basically what you write after the ip adress when in the browser or an APP.
This website has a great explanation of the ESP32 Arduino: Asynchronous HTTP web server
https://techtutorialsx.com/2017/12/01/esp32-arduino-asynchronous-http-webserver/
So... 
- First parameter here is: "/" thats the root directory.
- Second parameter is HTTP_GET thats an enum of type WebRequestMethod a method defined in the library here --> https://github.com/me-no-dev/ESPAsyncWebServer/blob/63b5303880023f17e1bca517ac593d8a33955e94/src/ESPAsyncWebServer.h
- Third parameter is a the function AsyncWebServerRequest
So there is this c++ lambda function used here. My litle understanding is that they are locally declared unamed function this means they dont have a name and are declared locally :-)
 I don't grasp the concept fully haha.
 the syntax is [captures](params){body} where in here [] is empity
*/

  // Route for root / web page
  server.on("/", HTTP_GET, [](AsyncWebServerRequest *request){
    request->send(SPIFFS, "/index.html", String(), false, processor);
  });

  server.on("/temp.html", HTTP_GET, [](AsyncWebServerRequest *request){
    request->send(SPIFFS, "/temp.html", String(), false, processor);
  });

  server.on("/farmtimenow", HTTP_GET, [](AsyncWebServerRequest *request){
    request->send_P(200, "text/plain", printShortFarmTime().c_str());
  });
  server.on("/temperature", HTTP_GET, [](AsyncWebServerRequest *request){
    request->send_P(200, "text/plain", readDHTTemperature().c_str());
  });
  server.on("/humidity", HTTP_GET, [](AsyncWebServerRequest *request){
    request->send_P(200, "text/plain", readDHTHumidity().c_str());
  });
  
 // Send a GET request to <ESP_IP>/update?relay=<inputMessage>&state=<inputMessage2>
  server.on("/update", HTTP_GET, [] (AsyncWebServerRequest *request) {
    String inputMessage;
    String inputParam;
    String inputMessage2;
    String inputParam2;
    // GET input1 value on <ESP_IP>/update?relay=<inputMessage>
    if (request->hasParam(PARAM_INPUT_1) & request->hasParam(PARAM_INPUT_2)) {
      inputMessage = request->getParam(PARAM_INPUT_1)->value();
      inputParam = PARAM_INPUT_1;
      inputMessage2 = request->getParam(PARAM_INPUT_2)->value();
      inputParam2 = PARAM_INPUT_2;
      if(RELAY_NO){
        Serial.print("NO ");
        digitalWrite(relayGPIOs[inputMessage.toInt()-1], !inputMessage2.toInt());
      }
      else{
        Serial.print("NC ");
        digitalWrite(relayGPIOs[inputMessage.toInt()-1], inputMessage2.toInt());
      }
    }
    else {
      inputMessage = "No message sent";
      inputParam = "none";
    }
    Serial.println(inputMessage + inputMessage2);

    //This is the last part of the lambda function. 
    //This method receives as first input the HTTP response code, which will be 200 in our case.  This is the HTTP response code for “OK”.
    request->send_P(200, "text/plain", "OK");
  });

  // Start server here
  server.begin();
}

void loop(){

}



String readDHTTemperature() {
  // Sensor readings may also be up to 2 seconds 'old' (its a very slow sensor)
  // Read temperature as Celsius (the default)
  float t = dht.readTemperature();
  // Read temperature as Fahrenheit (isFahrenheit = true)
  //float t = dht.readTemperature(true);
  // Check if any reads failed and exit early (to try again).
  if (isnan(t)) {    
    Serial.println("Failed to read from DHT sensor!");
    return "--";
  }
  else {
    Serial.println(t);
    return String(t);
  }
}

String readDHTHumidity() {
  // Sensor readings may also be up to 2 seconds 'old' (its a very slow sensor)
  float h = dht.readHumidity();
  if (isnan(h)) {
    Serial.println("Failed to read from DHT sensor!");
    return "--";
  }
  else {
    Serial.println(h);
    return String(h);
  }
}

// Replaces placeholder with button section in your web page
String processor(const String& var){
  //Serial.println(var);
  if(var == "BUTTONPLACEHOLDER"){
    String buttons ="";
    for(int i=1; i<=NUM_RELAYS; i++){
      String relayStateValue = relayState(i);
      //Here parts of the HTML will be parsed to index.html like Relay # followed by its value in variable for the GPIO numbers
      buttons+= "<h4>Turn on water on " + String(i) + "</h4><h4>Valve (relay) #" + String(i) + " - GPIO " + relayGPIOs[i-1] + "</h4><label class=\"switch\"><input type=\"checkbox\" onchange=\"toggleCheckbox(this)\" id=\"" + String(i) + "\" "+ relayStateValue +"><span class=\"slider\"></span></label>";
    }
    return buttons;
  }
  else if(var == "FARMTIMENOW"){
    return printShortFarmTime();
  }
  else if(var == "TEMPERATURE"){
    return readDHTTemperature();
  }
  else if(var == "HUMIDITY"){
    return readDHTHumidity();
  }
  return String();
}

String relayState(int valveRelayNum){
  if(RELAY_NO){
    if(digitalRead(relayGPIOs[valveRelayNum-1])){
      return "";
    }
    else {
      return "checked";
    }
  }
  else {
    if(digitalRead(relayGPIOs[valveRelayNum-1])){
      return "checked";
    }
    else {
      return "";
    }
  }
  return "";
}

//this function was found here https://arduino.stackexchange.com/questions/52676/how-do-you-convert-a-formatted-print-statement-into-a-string-variable
//I did a minor change so instead of a void function it now returns a string to be used to show time in the webinterface
String printFarmTime()
{
  time_t rawtime;
  struct tm timeinfo;
  getLocalTime(&timeinfo);
  char timeStringBuff[50]; //50 chars should be enough
  strftime(timeStringBuff, sizeof(timeStringBuff), "%A, %B %d %Y %H:%M:%S", &timeinfo);
  //print like "const char*"
  Serial.println(timeStringBuff);

  //Construct to create the String object 
  String timeAsAString(timeStringBuff);
  return timeAsAString;
}
String printShortFarmTime()
{
  time_t rawtime;
  struct tm timeinfo;
  getLocalTime(&timeinfo);
  char timeStringBuff[50]; //50 chars should be enough
  strftime(timeStringBuff, sizeof(timeStringBuff), "%H:%M:%S", &timeinfo);
  //print like "const char*"
  Serial.println(timeStringBuff);

  //Construct to create the String object 
  String timeAsAString(timeStringBuff);
  return timeAsAString;
}

void modifiedPrintLocalTime()
// Function based on post in the https://forum.arduino.cc/index.php?topic=536464.0 Arduino Forum by user Abhay
{ 
    int OnlyYear;
    int onlyMonth;
    int onlyDay;
    int onlyHour;
    int onlyMin;
    int onlySec;
    
    struct tm timeinfo;
    if(!getLocalTime(&timeinfo)){
        Serial.println("Failed to obtain time");
        return;
        }
//Serial.println(&timeinfo, "%m %d %Y / %H:%M:%S");
//scanf(&timeinfo, "%m %d %Y / %H:%M:%S")
        onlyHour = timeinfo.tm_hour;
        onlyMin  = timeinfo.tm_min;
        onlySec  = timeinfo.tm_sec;
        onlyDay = timeinfo.tm_mday;
        onlyMonth = timeinfo.tm_mon + 1;
        OnlyYear = timeinfo.tm_year +1900;
        
        //test
        Serial.print("Print only Hour and Minutes");
        Serial.print(onlyHour);
        Serial.print(":");
        Serial.print(onlyMin);
        }

int gimeTime(char what) {

    int OnlyYear;
    int onlyMonth;
    int onlyDay;
    int onlyHour;
    int onlyMin;
    int onlySec;

    struct tm timeinfo;
    if(!getLocalTime(&timeinfo)){
      Serial.println("Failed to obtain time");
      //return;
      }
    onlyHour = timeinfo.tm_hour;
    onlyMin  = timeinfo.tm_min;
    onlySec  = timeinfo.tm_sec;
    onlyDay = timeinfo.tm_mday;
    onlyMonth = timeinfo.tm_mon + 1;
    OnlyYear = timeinfo.tm_year +1900;

    switch (what) {
      case 1:
      return onlyHour;
      break;
      case 2:
      return onlyMin;
      break;
      case 3:
      return onlySec;
      break;
      default:
    // if nothing else matches, do the default
    // default is optional
    break;
    }
}

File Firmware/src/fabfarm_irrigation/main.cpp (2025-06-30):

#include "Config.h"

void setup()
{
  Serial.begin(9600);
  ElegantOTA.begin(&server);
  setupStorage();
  readDataJson();
  configureWiFiSettings();
  scanAvailableWiFiNetworks();
  initiateWiFiConnection();
  disableAllDevices();
  printCompilationTimestamp();
  initializeRtc();
  initializeServer();
  serverHandle();
}

void loop()
{
  // Handle OTA updates
  ElegantOTA.loop();
  handleWiFiConnection();
  
  // Run irrigation logic if in schedule mode
  if (isScheduleMode)
  {
    scheduleMode();
  }
}

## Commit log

2020-06-15 one page
    One page only for temp, humidity and time together activations of relays
2020-06-17 adding features into index.html. need help with JS bug
    [fabfarm_irrigation.ino]
2020-06-17 add README.md and try to fix html
    [fabfarm_irrigation.ino]
2020-06-18 Revert "updates"
    This reverts commit 29ba24a5f4c021fb44f9e41ddd7c0519eee81153.
    [fabfarm_irrigation.ino]
2020-06-18 Revert "add README.md and try to fix html"
    This reverts commit 015f7fb58bfb6b4e50fa05b1c896f6e75460d7ca.
    [fabfarm_irrigation.ino]
2020-06-18 Revert "adding features into index.html. need help with JS bug"
    This reverts commit b84a338d112b8ed323edd0073b4a52574d56285e.
    [fabfarm_irrigation.ino]
2020-06-21 working POC for json serialize / deserialize with arduinoJson
2020-06-21 Adds working update endpoint
    - Fixed issue with /update endpoint not working (is update a reserved term?) --> switched updateData
    [fabfarm_irrigation.ino]
2020-06-23 Fix time, sensors, start logic test still need to find out why jason override value doesnt apear good
    [fabfarm_irrigation.ino]
2020-06-23 fix bugs introduced from merges
    [fabfarm_irrigation.ino]
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2020-06-24 progress save on scheduling
    need to break apart time and compare to current time
2020-06-25 updates
    sucssessifully parsing the json to c++ already in int for the start time and duration
    matrix logic test tested! its good prints well all parameters
    next is to make the start logic
2020-06-25 Update fabfarm_irrigation.ino
    It works! needs cleaning up and solve bug that wipes json after refresh of browser.
    [fabfarm_irrigation.ino]
2020-06-26 dealing with issue #10
    -changed from while to if (WiFi.status() != WL_CONNECTED) and placed in the loop instead of setup adding a message for the case it connected.
    Tested i my setup it works.
    -added message of wich sone is active.
    [fabfarm_irrigation.ino]
2020-06-26 #6 solved
    fixed logic in function scheduleMode()
    [fabfarm_irrigation.ino]
2020-06-26 now #6 is fixed
    [fabfarm_irrigation.ino]
2020-06-26 fixed bug introduced on last commits
    [fabfarm_irrigation.ino]
2020-06-27 #11 attempt to add pump on/offalong with valves
    - included pumpPin 33 and its declarations
    - Included digitalWrite on each case
    - modified names from override to isScheduleMode
    ps: its not working as expected, the pumpPin keps going low ... high ... low... high
    @jknight I know its bad code, need to sleep, will leave here safe at the hands of github...
    [fabfarm_irrigation.ino]
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2020-06-28 #11 Pump now enable / disables as expected.
2020-06-30 Started drawing the PCB and added licence
    [esplash.sch]
2020-07-02 PCB updates
    [esplash.brd]
2020-07-02 update on Schematics of PCB
    [esplash.brd, esplash.sch]
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2020-07-16 creating enclosure
    [E-SPlash_project.SLDASM, box_bottom.SLDPRT, box_top.SLDPRT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]
2021-04-28 Working on the WIFI bug and setting up a new way to update the time
    [fabfarm_irrigation.ino]
2021-04-29 trying to fix wifi bug and refresh bug
    [fabfarm_irrigation.ino]
2021-05-01 PCB changes
    [esplash.brd, esplash.sch, esplashbpk.brd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]
2021-05-07 Html/ json communication fail
    [fabfarm_irrigation.ino]
2021-05-10 new board
    [esplash.brd, esplash.csv]
2021-05-10 solved ArduinoJson corruption in data.json file
    The problem was the version.
    Solution downgrade version on Arduino.ini to ArduinoJson@6.15.2
2021-05-11 First try adding relay table in setup interface
2021-05-11 reverting changes and cleanup
    reversing changes in functions done by @carlosmouracorreia until bug mentioned at commit 75f2494 is solved
    [fabfarm_irrigation.ino]
2021-05-14 Solved the freezing time problem but need to reset each time the time is modified (to be improved)
    [fabfarm_irrigation.ino]
2021-05-17 no freezing time without external declaration
    but still needs to reset for time change
    [fabfarm_irrigation.ino]
2021-05-19 cleaning and improving setup page
    working on adding and removing relays from setup page
2021-05-21 improving relay table in settup page
    improving relay table in settup page and updating sample json
2021-05-22 Add relay and delete relay buttons working
    add / delete relay buttons are working now, still need to link the relays in the setup page to the the index page, and add a table in settup page to show available pins
2021-07-04 added support for relays with TTL Logic LOW and cleanup
    included option to use relays with TTL Logic LOW
    improve readability and cleanup
2021-07-18 tossing internet time and manual time in favor of External RTC time
    due to instability of network relaying on having internet all the time is a big issue.
    Still have to solve softap problems
    [fabfarm_irrigation.ino]
2021-07-25 adding title to pages, update json sample and attempt to have favicon
2021-07-26 separated the scripts in order to prevent constant refresh on the sliders.
    [fabfarm_irrigation.ino]
2021-07-26 added function to write first json file in case it does not exist.
    added function to write data.json file in case it does not exists,
    It uses the file sample.json to create a first data.json file.
2021-08-24 fixing wifi bug that prevented from being connected from a smartphone
    [fabfarm_irrigation.ino]
2021-08-24 created pcb profiles with if def and clean up code
    created pcb profiles with if def and clean up code removing function previously used to reconnect
2021-09-14 reduction of web page refresh rate from 1s to 10s and fix of the /getdata route by using a copy of jsondocument to serialize instead of a cast
    [fabfarm_irrigation.ino]
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2021-09-16 correcting parameters of prototype board
    [fabfarm_irrigation.ino]
2021-09-19 Added a few credentials for wifi and changed DHT sensor settings
2022-02-21 Hardcoded DHCP mode
    Hardcoded DHCP mode to enable fixed IP one needs to uncomment the added comments in this commit.
    [fabfarm_irrigation.ino]
2022-03-03 fixing introduced bug that was crashing the execution of the code.
    origin of the crashes was an void added before the function initWiFi
    [fabfarm_irrigation.ino]
2022-03-07 Improvements to DHT sensor, manual and scheduled mode, saving JSON file
    Add None type for DHT type configuration when no DHT sensor is
    installed. Only read DHT sensor when one is configured.
    Keep global varable for scheduled mode. Only execute manual mode
    function on startup and whenever a relay is enabled/disabled. Run
    scheduled mode only onze per second.
    Return HTTP error when in scheduled mode and manually enabling/disabling
    relay
    Created new function for writing JSON file
    [fabfarm_irrigation.ino]
2022-03-08 Using off and on to represent the state is more accurate instead of low and high
    some relays modules can be activated either with an low or a high signal so using off and on to represent the state is more accurate
2022-03-10 HTML validation results, local bootstrap
    Validated the HTML with w3c.org HTML Checker and solved found errors.
    Bootstrap library is now hosted from device, and not from Content
    Delivery Network.
    Moved Scheduling Mode HTML element from JavaScript into the HTML file
2022-03-10 Cleand up sample JSON file
    Removed obsolete key value pairs
    Use true/false for boolean vales instead of 1/0
    Use numbers for numeric values instead of strings
2022-03-10 Fix rendering the relay times
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2022-03-25 Fix time calculation error
    [fabfarm_irrigation.ino]
2022-06-04 fix typo make library versions persistent
    [fabfarm_irrigation.ino]
2023-02-19 better comments and struct for board selection
    modified board selection with struct to improve understanding of the code. improved and added comments
2023-06-17 remove unused functions replace spiffs to litleFS
    [TimeHandler.cpp, WebServerManager.cpp, WiFiHandler.cpp]
2023-06-19 modify for litleFS, fix bug, refactor jsonHandler
    [RelayHandler.cpp, TimeHandler.cpp, WiFiHandler.cpp]
2023-06-23 increase interval read sensor solve constant crash
2025-02-01 add version to arduinoJson to prevent breaking changes
2025-06-29 Clean sensor-free irrigation system - removed ElegantOTA, DHT sensors, voltage sensors
2025-06-29 Hardware configuration cleanup: hard-coded relay pins in platformio.ini and simplified board config
    - Added relay pins as build flags: RELAY1_PIN=27, RELAY2_PIN=26, RELAY3_PIN=25, PUMP_PIN=13
    - Simplified BoardConfig to single configuration without hardware variants
    - Updated sample.json to use correct relay pins (27, 26, 25)
    - Ready for further simplification of relay management UI
2025-06-29 Fix pump pin: corrected from 13 to 33 to match PCB hardware
    Pin 33 is the correct pump pin as hardwired on the PCB hardware.
    Previous pin 13 was incorrect for this board configuration.
2025-06-29 Add AI coding guidelines for project architecture
    - Emphasizes keeping main.cpp clean and modular
    - Prohibits delay() functions on ESP32 with web servers
    - Documents fixed hardware pin configuration
    - Establishes clear modular architecture rules
    - Provides specific do's and don'ts for future AI assistants
2025-06-29 Implement automatic internet time synchronization with NTP
    Features:
    - Initialize NTP during RTC setup with multiple reliable servers
    - Perform initial sync on WiFi connection during startup
    - Automatic hourly sync when WiFi is connected
    - Non-blocking implementation using millis() timing
    - Updates both internal ESP32 RTC and external DS3231 RTC
    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
2025-06-29 Remove unused pin definitions from platformio.ini
    - Removed I2C_SDA_PIN and I2C_SCL_PIN (unused, I2C pins hardcoded in Config.cpp)
    - Removed RTC_IRQ_PIN (unused, no interrupt handling)
    - Removed BAT_VOLT_PIN (unused, no battery voltage monitoring)
    - Removed NUM_RELAYS (unused in codebase)
    - Simplified configurations to only include necessary GPIO pins for relay control
2025-06-29 Add timezone selection feature with UTC offset configuration
    - Added UTC offset dropdown to setup page (UTC-12 to UTC+12)
    - Updated TimeHandler to read timezone from JSON configuration
    - Added updateTimezone() function for runtime timezone changes
    - Modified WebServerManager to handle timezone updates
    - Set default UTC+1 for Portugal
    - Implemented non-blocking time synchronization
    - Fixed timezone being 1 hour behind issue
    [TimeHandler.cpp, WebServerManager.cpp, WiFiHandler.cpp]
2025-06-29 Remove pin configuration from JSON - use hardcoded hardware pins
    - Removed initializeHardwarePins() function from JsonHandler
    - Updated RelayHandler to use hardcoded pins (RELAY1_PIN, RELAY2_PIN, RELAY3_PIN)
    - Removed pin fields from sample.json since pins are hardware-specific
    - Pins are now defined in platformio.ini and cannot be changed by users
    - This prevents configuration conflicts and enforces hardware constraints
    [RelayHandler.cpp, main.cpp]
2025-06-29 Remove unused Board_Config files
    - Deleted empty Board_Config.h and Board_Config.cpp files
    - These files were not referenced anywhere in the codebase
    - Build system now relies entirely on platformio.ini build flags
    - Reduces clutter and simplifies project structure
2025-06-29 Optimize scheduling system with event-driven approach
    - Implement event-driven scheduling to eliminate serial output flooding
    - Add getNextScheduleEventTime() function to calculate next schedule events
    - Replace constant schedule checking with smart event-based triggers
    - Add state tracking to prevent redundant relay operations and logging
    - Implement smart frontend polling (10s/60s intervals based on schedule proximity)
    - Remove debug output spam from WebServerManager handleGetDataJsonRequest
    - Add fallback schedule checking every 60 seconds as safety measure
    - Maintain precise schedule execution while reducing CPU usage
    Fixes excessive '/data.json' serial output caused by 1-second fronten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
    [RelayHandler.cpp, WebServerManager.cpp, main.cpp]
2025-06-29 Add Over-The-Air (OTA) update functionality
    - Add OTAHandler.h and OTAHandler.cpp for wireless firmware updates
    - Integrate ArduinoOTA library with secure password authentication
    - Configure OTA hostname as 'esp32-irrigation' for easy network discovery
    - Add safety features: disable all devices during OTA updates
    - Implement OTA progress reporting and error handling callbacks
    - Integrate OTA initialization in main.cpp after WiFi connection
    - Prevent irrigation operations during active OTA updates
    - Add ArduinoOTA dependency to platformio.ini for both environments
    - Enable mDNS-based device discovery for seamless wireless updates
    - Secure password-protected OTA updates (password: i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
    [main.cpp]
2025-06-30 Remove OTA functionality from irrigation system
    - Deleted OTAHandler.h and OTAHandler.cpp files
    - Removed OTA includes from Config.h
    - Removed initializeOTA() and handleOTA() calls from main.cpp
    - Removed ArduinoOTA library dependency from platformio.ini
    - Simplified main loop by removing OTA active checks
    - Project now compiles successfully without OTA functionality
2025-06-30 Fix UI issues and clean up relay configuration
    - Remove undefined pin references from HTML display
    - Clean up relay configuration in setup page (relays are now hardware-fixed)
    - Remove relay add/remove functionality since relays are physically connected
    - Improve WiFi credentials UI with better messaging
    - Remove unused JavaScript functions for relay management
    - Update relay display to show only zone names without pin information
    - Prepare infrastructure for proper WiFi credential management
    Fixes:
    - Pin references showing 'undefined' in web interface
    - Confusing relay configuration options for fixed hardware
    - Inconsistent WiFi credentials update mechanism
    [main.cpp]
2025-06-30 feat: Complete UI redesign with modern agricultural theme and enhanced functionality
    🎨 Design Improvements:
    - Implemented modern glass-morphism design with agricultural gradient background
    - Large prominent logo with white background for better visibility
    - Consistent design language across main page and setup page
    - Mobile-first responsive design optimized for phone screens
    - Professional typography with proper visual hierarchy
    🚀 Performance Enhancements:
    - Reduced polling intervals for 6x faster responsiveness (5s manual, 3s near schedules)
    - Real-time feedback for relay controls and system status
    - Smart polling system that adapts to schedule proximity
    - Optimized UI updates to pre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
    [WebServerManager.cpp, storageHandler.cpp]
2025-07-01 fix: Configure inverted relay logic for custom PCB hardware
    🔧 Hardware Configuration Updates:
    - Added INVERT_RELAY_LOGIC build flag for esp32doit-devkit-v1 configuration
    - Custom PCB (pins 27,26,25,33) now uses inverted logic (LOW = ON, HIGH = OFF)
    - LILYGO T-Relay 4CH (pins 21,19,18,5) maintains standard logic (HIGH = ON, LOW = OFF)
    📋 Technical Details:
    - Updated platformio.ini to include -DINVERT_RELAY_LOGIC flag for custom PCB
    - Modified Config.h to handle conditional relay logic compilation
    - Replaced TTL_Logic_Low with cleaner INVERT_RELAY_LOGIC flag system
    - Both hardware configurations compile and work correctly
    🎯 Result:
    - Custom PCB hardware: Relay logic inverted (opposit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
2025-08-11 Refactor and modernize the frontend UI.
    This commit overhauls the user interface of the web application served by the ESP32. The changes include:
    - Consolidating all CSS styles into a single, unified stylesheet (`modern-style.css`).
    - Removing inline styles from `index.html`.
    - Extracting inline JavaScript from `setuppage.html` into a separate `setup.js` file.
    - Modernizing the JavaScript to use the `fetch` API instead of the older `XMLHttpRequest`.
    - Updating all asset paths to be relative, ensuring compatibility with file-based viewing for testing.
2025-08-11 This commit enhances the irrigation system's scheduling capabilities and further modernizes the user interface.
    New Features:
    - Adds day-of-the-week scheduling, allowing you to select specific days for each watering cycle.
    UI/UX Improvements:
    - Implements a new, modern color scheme for a cleaner look and feel.
    - Redesigns the schedule editor to be more intuitive and include the new day picker.
    Backend Changes:
    - Updates the C++ logic in RelayHandler.cpp to process the new day-of-the-week schedule information.
    - Modifies the JSON data structure to include a "days" array for each schedule.
    Frontend Changes:
    - Updates the JavaScript in script.js to manage the new day picker UI and send the u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
    [RelayHandler.cpp]
2025-08-11 feat: Add manual mode function to relay handler and create setup CSS file

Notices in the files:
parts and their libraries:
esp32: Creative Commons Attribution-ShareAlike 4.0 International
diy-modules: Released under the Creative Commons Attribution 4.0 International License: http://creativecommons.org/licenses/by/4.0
